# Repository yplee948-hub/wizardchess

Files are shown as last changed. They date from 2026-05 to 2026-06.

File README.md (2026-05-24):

# Wizard Chess

A Harry Potter-style physical chess board that moves pieces autonomously using an electromagnet on a CoreXY gantry. Players interact via voice command or a web UI — the board physically slides the pieces to match the move.

## How It Works

```
Browser (Next.js UI)
        │
        │  WebSocket (LAN)
        ▼
ESP32-S3 (control_firmware)   ◄──── I2S Microphone (voice → Whisper)
        │
        │  UART @ 115200
        ▼
Raspberry Pi Pico (motor_firmware)
        │
        ▼
CoreXY gantry + Electromagnet
```

1. A player speaks a move ("e2 to e4") or clicks it in the UI.
2. The **ESP32-S3** transcribes voice via OpenAI Whisper (or receives it over WebSocket) and forwards it to the Pico.
3. The **Pico** validates the move, plans the physical path, and drives the CoreXY stepper motors and electromagnet to move the piece.
4. Game state lives on the Pico and is relayed back to the UI in real time.

## Repository Structure

```
wizardchess/
├── motor_firmware/      # Raspberry Pi Pico — CoreXY motion + chess game logic
├── control_firmware/    # Seeed XIAO ESP32-S3 — voice + WebSocket bridge (ESP-NOW to motor)
├── UI/                  # Next.js web UI + WebSocket broker (only copy — do not duplicate)
├── prints/              # KiCad PCB + gerbers (STLs on OneDrive)
└── README.md            # This file
```

> **Web UI:** Use the `UI/` folder only. If you download a separate “web interface” zip, merge into `UI/` or replace it — do not add a second top-level copy.

## Hardware Required

| Component | Role |
|---|---|
| Raspberry Pi Pico (RP2040) | Motor control + game logic |
| Seeed XIAO ESP32-S3 | Voice recognition + Wi-Fi bridge |
| 2× Stepper motors (+ driver) | CoreXY X/Y motion |
| Electromagnet (H-bridge driven) | Piece pickup |
| ICS-43432 I2S microphone | Voice input |
| Custom motor PCB | Integrates Pico + drivers |

## Quick Start

See the README in each subdirectory for full setup instructions:

- [`motor_firmware/`](motor_firmware/README.md) — flash the Pico first
- [`control_firmware/`](control_firmware/README.md) — flash the ESP32-S3 second
- [`UI/`](UI/README.md) — run the web interface last
## Fabrication Files (Prints)

STL models, resin slicer files (.ctb), KiCad PCB, laser cut SVGs, and Fusion 360 source files are stored on OneDrive (too large for git):

**[Open OneDrive folder](https://uwnetid-my.sharepoint.com/:f:/r/personal/ktaing_uw_edu/Documents/wizard_chess?csf=1&web=1&e=kmWmI7)**

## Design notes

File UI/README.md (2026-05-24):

# Wizard Chess — Web UI

Next.js app for the physical board: intro screen, playable board, Stockfish opponent, and a WebSocket broker that talks to the ESP32-S3 control firmware.

## Prerequisites

- Node.js 20+
- ESP32-S3 flashed with [`control_firmware`](../control_firmware/README.md) (set `UI_SERVER_IP` in `config.h` to this machine’s LAN IP)

## Setup

```bash
cd UI
npm install
cp ../control_firmware/src/config.h.example ../control_firmware/src/config.h   # if not done yet — edit Wi‑Fi/API keys on the ESP32 side
```

Optional env (`.env.local`):

| Variable | Default | Purpose |
|---|---|---|
| `PORT` | `3000` | Next.js HTTP |
| `BROKER_PORT` | `3001` | WebSocket broker |
| `NEXT_PUBLIC_WS_URL` | `ws://<hostname>:3001/ws` | Override WS URL in the browser |

## Run

```bash
npm run dev
```

- UI: http://localhost:3000  
- Broker: `ws://localhost:3001/ws` (browser) · `ws://<your-lan-ip>:3001/device` (ESP32)

Open the UI from another device on the same Wi‑Fi using `http://<laptop-ip>:3000` — the client picks up the broker host automatically.

## Scripts

| Command | Description |
|---|---|
| `npm run dev` | UI + broker (`server.mjs`) |
| `npm run build` | Production Next.js build |
| `npm run start` | Production UI + broker |
| `npm run lint` | ESLint |
| `node test-device.mjs` | Quick broker/device smoke test |

## Layout

```
UI/
├── app/              # Next.js App Router (intro + /game)
├── public/           # SVG pieces, intro assets, Stockfish WASM
├── scripts/          # Stockfish copy helper, ws-test.html
├── server.mjs        # HTTP (3000) + WebSocket broker (3001)
└── test-device.mjs   # Broker connectivity helper
```

See [root README](../README.md) for full system architecture and flash order.

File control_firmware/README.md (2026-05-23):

# Control Firmware

Runs on the **Seeed XIAO ESP32-S3**. Acts as the central brain: transcribes voice commands via OpenAI Whisper, hosts a WebSocket server for the web UI, and relays everything to the Pico over UART.

## What It Does

- Listens for a button press, records up to 3 seconds of audio via I2S microphone
- Sends the audio to OpenAI Whisper and parses the transcript for a chess move ("e2 to e4")
- Hosts a WebSocket server so the Next.js UI can send moves and receive live game events
- Forwards move commands to the Pico (`MOVE:E2:E4`) and relays Pico responses back to the UI
- Voice and UI commands are interchangeable — the Pico can't tell them apart

## Hardware

**Board:** Seeed XIAO ESP32-S3

| Component | Pins |
|---|---|
| I2S Mic DOUT / BCLK / LRCLK | D0, D1, D2 |
| Record button (BOOT, active LOW) | D3 |
| UART TX to Pico / RX from Pico | D4, D5 |

**Required hardware:**
- ICS-43432 (or compatible) I2S MEMS microphone
- Wi-Fi access to the same LAN as the laptop running the UI

## Configuration

Credentials are kept out of source control. Before building:

```bash
cp src/config.h.example src/config.h
```

Edit `src/config.h`:

```cpp
#define WIFI_SSID       "your_network_name"
#define WIFI_PASSWORD   "your_wifi_password"
#define OPENAI_API_KEY  "sk-proj-..."
```

`src/config.h` is gitignored and will never be committed.

## Building & Flashing

Requires [PlatformIO](https://platformio.org/).

```bash
cd control_firmware
pio run --target upload
```

Update the upload port in `platformio.ini` if `/dev/cu.usbmodem14301` doesn't match your system.

**Dependencies** (auto-installed):
- `bblanchon/ArduinoJson`
- `mathieucarbou/AsyncTCP`
- `mathieucarbou/ESPAsyncWebServer`

## Usage

1. Flash the firmware and open a serial monitor at **115200 baud**.
2. The ESP32 connects to Wi-Fi and prints its IP address — note it for the UI.
3. Press the **BOOT button** to record a move. Speak clearly: *"e2 to e4"*.
4. The firmware transcribes, parses, and sends the move to the Pico automatically.

Alternatively, the Next.js UI connects to `ws://<esp32-ip>/ws` and sends moves directly.

## WebSocket API

The ESP32 hosts a WebSocket at `ws://<device-ip>/ws`.

### UI → ESP32

```json
{ "type": "move",  "from": "E2", "to": "E4" }
{ "type": "reset" }
{ "type": "hello" }
```

### ESP32 → UI

```json
{ "type": "ack",     "from": "E2", "to": "E4" }
{ "type": "illegal", "from": "E2", "to": "E4", "reason": "..." }
{ "type": "done",    "from": "E2", "to": "E4" }
{ "type": "turn",    "color": "WHITE" }
{ "type": "state",   "board": "rnbqkbnr...w" }
{ "type": "log",     "text": "..." }
```

## Source Layout

```
src/
├── main.cpp        # Button handler, recording pipeline, Whisper call, move parser
├── pico_link.cpp/h # UART protocol to/from the Pico
├── ui_link.cpp/h   # WebSocket server (ESPAsyncWebServer)
└── config.h        # Credentials (gitignored — copy from config.h.example)
```

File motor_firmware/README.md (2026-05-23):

# Motor Firmware

Runs on the **Raspberry Pi Pico (RP2040)**. Owns the chess game state, validates moves, plans the physical piece path, and drives the CoreXY gantry and electromagnet.

## What It Does

- Maintains a full chess game (legal move validation, turn tracking, board state)
- Receives move commands from the ESP32-S3 over UART (`MOVE:E2:E4`)
- Plans the physical path — routing around pieces, lifting/lowering the electromagnet
- Drives two stepper motors in CoreXY kinematics to move the carriage
- Emits game events back to the ESP32-S3 (`ACK`, `DONE`, `TURN`, `STATE`)

## Hardware

**Board:** Raspberry Pi Pico (RP2040)

| Component | Pins (GPIO) |
|---|---|
| Motor A (enable / step / dir) | GPIO 2, 3, 4 |
| Motor B (enable / step / dir) | GPIO 18, 19, 20 |
| Electromagnet (IN1 / IN2 / ENA) | GPIO 6, 7, 8 |
| UART to ESP32-S3 (TX / RX) | Serial2 (GPIO 4/5 default) |

**Motion specs:**
- Travel: ~41 cm × 41 cm
- Steps per axis: 16,400
- Square origin A1: (2.5 cm, 2.5 cm) from home
- Square spacing: 5.0 cm per column and row

## Building & Flashing

Requires [PlatformIO](https://platformio.org/) (CLI or VS Code extension).

```bash
cd motor_firmware
pio run --target upload
```

The board and upload port are set in `platformio.ini` (`board = pico`, port `/dev/cu.usbmodem144401`). Update the port to match your system if needed.

**Dependencies** (auto-installed by PlatformIO):
- `adafruit/Adafruit VEML7700 Library`

## UART Protocol

The Pico communicates with the ESP32-S3 over UART at **115200 baud**.

### Incoming (ESP32-S3 → Pico)

| Message | Meaning |
|---|---|
| `MOVE:<from>:<to>` | e.g. `MOVE:E2:E4` |
| `RESET` | Reset the game to starting position |
| `STATE?` | Request a full board state dump |

### Outgoing (Pico → ESP32-S3)

| Message | Meaning |
|---|---|
| `ACK:<from>:<to>` | Move accepted, motion starting |
| `DONE:<from>:<to>` | Motors finished, piece placed |
| `ILLEGAL:<reason>` | Move rejected |
| `TURN:<WHITE\|BLACK>` | Turn changed |
| `STATE:<board> <w\|b>` | 64-char board snapshot + side to move |
| `LOG:<text>` | Debug message |

## Source Layout

```
src/
├── main.cpp          # Setup, UART command dispatch, move loop
├── ChessGame.cpp/h   # Chess rules and board state
├── ChessTypes.h      # Piece and square types
├── CoreXY.cpp/h      # CoreXY kinematics
├── MovePlanner.cpp/h # Physical path planning around pieces
├── StepperMotor.cpp/h# Low-level stepper driver
└── Electromagnet.h   # Electromagnet H-bridge control
```

## Debugging

Open a serial monitor at **115200 baud** on the Pico's USB port. Protocol lines (`ACK`, `DONE`, etc.) go to `Serial2` (UART to ESP32); debug logs go to USB `Serial`.

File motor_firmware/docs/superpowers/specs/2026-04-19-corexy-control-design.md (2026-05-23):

# CoreXY Motion Control — Design

**Date:** 2026-04-19
**Target board:** Seeed XIAO ESP32-S3 (PlatformIO / Arduino)
**Scope:** High-level C++ API to drive a CoreXY rig using two existing `StepperMotor` instances.

## Goals

- Command motion by absolute XY coordinates in raw motor steps (no millimeter calibration).
- Produce straight-line motion at arbitrary angles (not L-shape).
- Support manual homing and soft limits (no physical endstops).
- Keep the API small, blocking, and easy to use from `main.cpp`.

## Non-goals

- No G-code parser, no serial command interface.
- No mm / physical-unit conversion.
- No per-move acceleration profile (fixed cruise speed only).
- No non-blocking / background motion.
- No physical limit switches.

## Architecture

Two components, cleanly separated:

1. **`StepperMotor`** (existing) — one new method added. Everything else unchanged.
   - New: `void stepOnce()` — strobes STEP HIGH for ~2 µs then LOW, increments the step counter. No cruise delay.
   - Existing `step()`, `steps()`, `rampUp()`, `setSpeed()`, `setDirection()`, `enable()`, `disable()`, `begin()` stay intact and usable for single-motor testing.

2. **`CoreXY`** (new) — composes two `StepperMotor` references, applies CoreXY kinematics, runs coordinated blocking moves, tracks position, enforces soft limits.

### Files

- `src/StepperMotor.h` / `src/StepperMotor.cpp` — add `stepOnce()`.
- `src/CoreXY.h` / `src/CoreXY.cpp` — new.
- `src/main.cpp` — rewrite to use `CoreXY`; keeps the existing `motorA(D4,D5,D6)` and `motorB(D9,D8,D7)` instances.

## Public API

```cpp
class CoreXY {
public:
    CoreXY(StepperMotor& motorA, StepperMotor& motorB);

    void begin();                              // enables both motors
    void setSpeed(int stepsPerSec);            // default 1500; applies to the next move

    void setInvertX(bool inv);                 // flip X direction sense in software
    void setInvertY(bool inv);                 // flip Y direction sense in software

    // Homing & bounds (no physical endstops)
    void setHome();                            // current position becomes (0, 0)
    void setMaxBounds(long xMax, long yMax);   // soft limits; 0 on an axis disables that bound
    void clearBounds();                        // remove all soft limits

    // Motion (blocking)
    void moveTo(long x, long y);               // absolute, coordinated straight line
    void moveBy(long dx, long dy);             // relative

    // State
    long getX() const;
    long getY() const;

    void disable();                            // disables both motor drivers
};
```

## Behavior

### Homing

- There are no physical switches. The user jogs (or places) the head at a chosen corner and calls `setHome()`, which zeroes the internal position.
- `setMaxBounds(xMax, yMax)` is called once (hardcoded after one-time manual calibration of the physical travel).

### Bounds enforcement

- `moveTo(x, y)` and `moveBy(dx, dy)` check the target against `[0..xMax, 0..yMax]` **before** moving.
- If the target is out of bounds, the call **refuses**: no steps issued, position unchanged, a short warning printed to `Serial` (e.g. `"[CoreXY] refused: target (1200, 0) out of bounds"`).
- `setMaxBounds(0, 0)` or never calling `setMaxBounds` means no limits — any target is accepted, including negative coordinates. User accepts responsibility for not crashing the head into the frame.

### Direction inversion

- `setInvertX(bool)` and `setInvertY(bool)` flip the sign of `ΔX` / `ΔY` in the kinematics calculation only. Internal position remains in user coordinates (so `moveTo(100, 0)` always means "go to X=100 in user space").
- Used to correct belt / wiring direction in software without changing hardware.

### Motor mapping

- `motorA` = first ctor argument; `motorB` = second.
- In the starter `main.cpp`: `motorA = StepperMotor(D4, D5, D6)`, `motorB = StepperMotor(D9, D8, D7)`.

## Kinematics & Stepping Algorithm

### Inverse kinematics

After applying inversion flags:

```
ΔA = ΔX + ΔY
ΔB = ΔX − ΔY
```

Direction pins are set once per move from the signs of `ΔA` and `ΔB`.

### Straight-line stepping (Bresenham)

CoreXY kinematics is linear, so a straight line in motor-step space `(A, B)` maps to a straight line in `(X, Y)`. Standard Bresenham:

- `aA = |ΔA|`, `aB = |ΔB|`.
- The axis with the larger step count is the "fast" axis; it pulses every iteration.
- The "slow" axis pulses only when an error accumulator overflows.
- Total iterations = `max(aA, aB)`.

### Timing

- `stepOnce()` on each motor does a ~2 µs STEP pulse (well above the minimum for A4988 / DRV8825 / TMC2208 drivers) and returns immediately.
- Between iterations, `CoreXY::moveTo()` calls `delayMicroseconds(period)` where `period = 1,000,000 / stepsPerSec`. At 1500 steps/sec → ~666 µs per iteration.
- Direction pins are set **once** at the start of the move.

### Edge cases

- `ΔA == 0 && ΔB == 0` → return immediately.
- Small moves (1–2 steps) → still go through the Bresenham loop; correct by construction.
- Position updates **only** after the loop completes successfully.

## `main.cpp` shape

```cpp
#include <Arduino.h>
#include "StepperMotor.h"
#include "CoreXY.h"

StepperMotor motorA(D4, D5, D6);
StepperMotor motorB(D9, D8, D7);
CoreXY xy(motorA, motorB);

void setup() {
    Serial.begin(115200);
    xy.begin();
    xy.setSpeed(1500);
    xy.setHome();
    // xy.setMaxBounds(5000, 3000);  // fill in after manual calibration

    xy.moveTo(1000, 0);
    xy.moveTo(1000, 1000);
    xy.moveTo(0, 1000);
    xy.moveTo(0, 0);
}

void loop() {}
```

## Testing plan

No host-side unit tests; validation is on the physical rig:

1. **Single-motor sanity** — confirm both motors spin correctly using the existing `StepperMotor` API in isolation.
2. **Pure-X move** — `moveTo(500, 0)`. Both motors step 500 in the same direction. Head moves along X. If it moves in Y, use `setInvertX` / `setInvertY` or re-pick which motor is A / B.
3. **Pure-Y move** — `moveTo(0, 500)`. Both motors step 500 in opposite directions. Head moves along Y.
4. **Diagonal** — `moveTo(500, 500)`. Motor A steps 1000, motor B steps 0. Head moves diagonally.
5. **Square** — run the demo in `main.cpp`; verify the head returns to the starting point (loop closes).
6. **Bounds** — `setMaxBounds(500, 500)` then `moveTo(1000, 0)` → serial prints a refusal; position unchanged.

## Open items / future work

- Non-blocking motion (`tick()`-driven) if later work needs to run sensors concurrently with motion.
- Trapezoidal acceleration per move if higher step rates cause skipped steps.
- Physical endstops + `home()` that actually drives into them, if the rig gains switches.

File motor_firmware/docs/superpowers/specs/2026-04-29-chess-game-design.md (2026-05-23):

# Chess Game Class Design

**Date:** 2026-04-29
**Project:** TECHIN 515 Group Final — Physical Chess Robot (CoreXY + Electromagnet)

---

## Overview

Two new C++ classes — `ChessGame` and `MovePlanner` — manage chess game state and physical move execution respectively. They are decoupled from `CoreXY` and `Electromagnet`: they produce data (board state, step sequences) that `main.cpp` acts on. This separation allows the classes to be tested on a PC or microcontroller without any motor hardware attached.

---

## Shared Types (`ChessTypes.h`)

```cpp
enum PieceType  { NONE, PAWN, ROOK, KNIGHT, BISHOP, QUEEN, KING };
enum PieceColor { WHITE, BLACK, NO_COLOR };

struct Piece    { PieceType type; PieceColor color; };
struct Position { char col; int row; };  // col 'A'–'H', row 1–8

struct PhysicalConfig {
    float originX, originY;  // physical XY of A1 in cm
    float stepX,   stepY;    // cm per square
};

enum StepType { MOVE_TO, MAGNET_ON, MAGNET_OFF };
struct Step   { StepType type; Position target; float x; float y; };
// x and y are only meaningful for MOVE_TO steps; set to 0 for MAGNET_ON/MAGNET_OFF
```

---

## `ChessGame`

### Responsibility
Owns the board state and enforces chess rules. Does not touch hardware or compute physical paths.

### Data
- `Piece board[8][8]` — 2D array indexed by column (0–7) and row (0–7)
- `PieceColor turn` — whose turn it is
- `std::vector<Piece> captured` — pieces that have been taken off the board

### Constructor / Initialization
```cpp
ChessGame();                        // standard starting position
ChessGame(Piece board[8][8]);       // custom starting position
void reset();                       // restore standard starting position
```

### Key Methods
```cpp
bool      isLegalMove(Position from, Position to);  // validates piece rules, turn, capture legality
bool      applyMove(Position from, Position to);    // updates board after physical move completes
PieceColor getTurn();
Piece     getPieceAt(Position pos);
bool      isEmpty(Position pos);
std::vector<Piece> getCaptured();
```

### Rules Implemented (core moves)
- Each piece type moves according to standard chess movement patterns
- A piece may not move to a square occupied by a friendly piece
- Capturing: moving to a square occupied by an enemy piece is legal (per piece rules)
- Turn alternation: WHITE moves first, turns alternate after each `applyMove()`
- **Not implemented:** castling, en passant, pawn promotion, check/checkmate/stalemate detection

### Notes
- `applyMove()` is called internally by `MovePlanner` at the moment `isMoveDone()` becomes true, keeping the board in sync with physical reality. `main.cpp` does not call it directly.
- Knight movement is rectilinear at the rules level (L-shape) but the physical path is still handled as rectilinear waypoints by `MovePlanner`.

---

## `MovePlanner`

### Responsibility
Holds a reference to `ChessGame` to read board state, computes a rectilinear physical path for a validated move, manages displaced and captured pieces, and exposes a step-by-step execution interface for sensor integration.

### Data
- `ChessGame& game` — reference to the game state
- `PhysicalConfig config` — physical grid constants
- `std::queue<Step> steps` — planned step sequence for the current move
- `BorderSlots capturedSlots` — registry of occupied/free parking slots around the board edge for captured pieces

### Physical Coordinate Mapping
```
physicalX(pos) = config.originX + (pos.col - 'A') * config.stepX
physicalY(pos) = config.originY + (pos.row - 1)  * config.stepY
```
Default values from current `main.cpp`: `originX=3.8`, `originY=5.5`, `stepX=5.0`, `stepY=5.0`.

### Path Planning Rules
- Paths are strictly rectilinear (horizontal then vertical, or vertical then horizontal — no diagonal movement)
- Direction chosen to minimize the number of blocking pieces on the primary leg
- For each blocking piece along the path: park it on the nearest orthogonally adjacent empty square (up/down/left/right only, no diagonal), complete the main move, then restore it
- Captured pieces are parked in the next free border slot around the board and tracked permanently

### Step Sequence (per move)
Each move compiles to an ordered queue of `Step` entries:
1. Sub-sequences for each blocking piece (MAGNET_ON → MOVE_TO park square → MAGNET_OFF)
2. MAGNET_ON → MOVE_TO destination → MAGNET_OFF for the main piece
3. Sub-sequences to restore each displaced blocking piece
4. If a capture: the captured piece sub-sequence runs before step 2, parking it at the border

### Key Methods
```cpp
MovePlanner(ChessGame& game, PhysicalConfig config);

bool startMove(Position from, Position to);  // plan full path; returns false if illegal
bool nextStep();                             // execute one Step, return true if more remain
bool isMoveDone();                           // true when step queue is empty
Step peekNextStep();                         // inspect next Step without advancing (for sensor hook)
```

### Sensor Integration Hook (future)
```cpp
// In main.cpp loop:
Step s = planner.peekNextStep();
// read hall effect sensor here — confirm piece presence if s.type == MOVE_TO
planner.nextStep();
// then act: xy.moveToCm(s.x, s.y) or magnet.on()/off()
```

---

## Integration in `main.cpp`

```cpp
ChessGame game;
MovePlanner planner(game, {3.8f, 5.5f, 5.0f, 5.0f});

// To make a move:
if (planner.startMove({'E', 2}, {'E', 4})) {
    while (!planner.isMoveDone()) {
        Step s = planner.peekNextStep();
        planner.nextStep();
        if (s.type == MOVE_TO)      xy.moveToCm(s.x, s.y);
        else if (s.type == MAGNET_ON)  magnet.on();
        else if (s.type == MAGNET_OFF) magnet.off();
    }
}
```

---

## File Structure

```
src/
  ChessTypes.h      — shared enums and structs
  ChessGame.h
  ChessGame.cpp
  MovePlanner.h
  MovePlanner.cpp
```

---

## Out of Scope (this spec)

- Castling, en passant, pawn promotion
- Check, checkmate, stalemate detection
- AI / computer opponent
- Hall effect sensor driver (integration point is defined, not implemented)

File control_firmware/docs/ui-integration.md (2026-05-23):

# UI ↔ ESP32-S3 ↔ Pico Integration — Design

## Goal

Let a Next.js chess UI drive (and stay in sync with) the physical board, while keeping the existing ESP32-S3 microphone input working. The ESP32-S3 is the brain: it accepts commands from both the UI and the mic, forwards canonical moves to the Pico, and relays the Pico's game-state feedback back up to the UI.

## Topology (LAN-only, no cloud)

```mermaid
flowchart LR
    UI["Next.js<br/>(browser)"]
    S3["ESP32-S3<br/>(brain + mic)"]
    Pico["Pico<br/>(motors + game)"]

    UI <-- "WebSocket (LAN)" --> S3
    S3 <-- "UART" --> Pico
```

- The laptop running `next dev` and the ESP32-S3 share the same Wi-Fi network.
- The ESP32-S3 runs a WebSocket server on its LAN IP, e.g. `ws://<s3-ip>/ws`.
- No remote server, no port forwarding, no auth (demo scope).
- Fallback option if venue Wi-Fi is hostile: run the S3 as a Wi-Fi Access Point ("ChessBot-AP") and have the laptop join it. Same protocol, different network plumbing.

## Source of truth

- **Game state lives on the Pico.** It already has `ChessGame` and a working move planner; we don't want two copies that can drift.
- The ESP32-S3 caches the last `STATE` message it saw from the Pico so it can hand it to a UI client that just connected. It is a relay + cache, not an authority.
- The UI waits for an `ACK` (or `ILLEGAL`) before animating a move. No optimistic UI for the demo — simpler and more honest about what the hardware actually did.

## Pico ↔ ESP32-S3: UART line protocol

Both sides at 115200 8N1 on the existing UART. Lines terminated with `\n`. Case-insensitive on the Pico side (it already uppercases input). Keep the protocol ASCII so it's debuggable with a serial monitor.

### S3 → Pico (commands)

| Line | Meaning |
|---|---|
| `MOVE:<from>:<to>` | e.g. `MOVE:E2:E4` |
| `RESET` | reset the game |
| `STATE?` | request a `STATE:` dump (for resync) |

### Pico → S3 (events)

| Line | Meaning |
|---|---|
| `ACK:<from>:<to>` | move accepted, motion starting |
| `ILLEGAL:<reason>` | move rejected by `ChessGame` or planner |
| `DONE:<from>:<to>` | motors + magnet finished the move |
| `TURN:<WHITE\|BLACK>` | turn changed (emitted after `DONE` and after `RESET`)  |
| `STATE:<compact-board>` | full board snapshot; emitted on boot, `RESET`, `STATE?`|
| `LOG:<text>` | optional human-readable diagnostics |

The `STATE` payload format is TBD — simplest is 64 chars in row-major order using standard piece letters (`PNBRQK`/`pnbrqk`/`.`), plus a trailing turn marker, e.g. `STATE:rnbqkbnr/...whatever... w`. FEN is fine if it's cheap to emit; we don't need castling/en-passant rights for the demo unless the game logic enforces them.

### Pico-side changes

- Today's `main.cpp` reads `MOVE:<from>:<to>` from `Serial1`. Keep that.
- Wrap the existing `Serial.print*` debug output into a small helper so the *protocol* lines (`ACK`, `DONE`, `STATE`, …) go to `Serial1` and casual debug logs go to USB `Serial` only. Mixing them on one stream is fine for the demo but easier to parse if separated.
- Emit `ACK` immediately after `planner.startMove` succeeds, `DONE` after the planner loop finishes, `TURN` after the turn flips, and `STATE` on boot / after `RESET` / on `STATE?`.

## ESP32-S3 ↔ UI: WebSocket protocol

JSON messages over a single WebSocket. The S3 hosts it (e.g. `ESPAsyncWebServer` + `AsyncWebSocket`). One endpoint, all traffic.

### UI → S3

```json
{ "type": "move",  "from": "E2", "to": "E4" }
{ "type": "reset" }
{ "type": "hello" }    // optional; S3 replies with current state
```

### S3 → UI

```json
{ "type": "ack",     "from": "E2", "to": "E4" }
{ "type": "illegal", "from": "E2", "to": "E4", "reason": "..." }
{ "type": "done",    "from": "E2", "to": "E4" }
{ "type": "turn",    "color": "WHITE" }
{ "type": "state",   "board": "<compact-or-fen>", "turn": "WHITE" }
{ "type": "log",     "text": "..." }              // optional
```

The mapping S3 does is mechanical: parse the UART line, wrap it as JSON, broadcast to all connected WS clients. In the other direction: parse JSON, format the UART line, write to the Pico. The S3 also handles the mic path the same way — mic recognizer produces a `{from, to}` pair, S3 sends `MOVE:` down. Voice and UI commands are indistinguishable to the Pico, which is the point.

### Connection lifecycle

1. UI opens the WebSocket.
2. S3 immediately sends the cached `state` (and current `turn`) so the new client renders the right board without polling.
3. UI sends `move` / `reset`; S3 forwards to Pico.
4. Pico replies with `ack` → `done` → `turn`; S3 fans those out to *all* WS clients (so two browsers on the same LAN stay in sync, and the UI reflects voice-initiated moves the same way).

## ESP32-S3 internal shape

Three input sources, one output (UART to Pico):

- Mic recognizer task → produces `{from, to}` or `reset`.
- WebSocket handler → produces `{from, to}` or `reset` from JSON.
- UART reader → produces parsed events from the Pico.

A small dispatcher serializes commands going *down* (don't interleave a mic move and a UI move mid-line) and broadcasts events going *up*. While a move is in flight (between `ACK` and `DONE`), new commands should be queued or rejected — TBD which; rejection with an `illegal` reason of `"busy"` is the simpler choice.

State cached on the S3:
- Last `state` payload (string).
- Current `turn`.
- Whether a move is in flight.

## Next.js side

- A single client component opens the WebSocket to `NEXT_PUBLIC_S3_WS_URL` (e.g. `ws://192.168.1.42/ws`) and keeps it open for the page's lifetime. Reconnect with backoff on close.
- Board state is driven entirely by `state` / `done` / `turn` messages — the UI does not maintain its own authoritative game state.
- Clicking a piece + target square sends `{ "type": "move", from, to }`. The UI marks the move as "pending" until `ack`/`illegal` arrives, then animates on `done`.
- A "Reset" button sends `{ "type": "reset" }`.

No Node API routes, no `serialport`, no server-side code beyond what Next already does to serve the page. All hardware I/O is in the S3.

## Decisions (locked for the POC)

- **`STATE` payload**: 64 chars, row-major from rank 8 down to rank 1, piece letters (`PNBRQK` white, `pnbrqk` black, `.` empty), followed by a space and the side to move (`w`/`b`). Whatever is cheapest to emit from `ChessGame`.
- **Busy**: while a move is in flight (between `ACK` and `DONE`), any new command is rejected with `ILLEGAL:busy`. No queue.
- **Promotion**: out of scope for the POC.
- **Discovery**: S3's IP is hardcoded in the Next.js client for the demo. S3 also prints its IP over USB serial on boot for convenience.

## Build order (suggested)

1. Pico: extend the UART protocol with `ACK` / `DONE` / `TURN` / `STATE` / `STATE?` / `ILLEGAL`. Verify with a serial monitor by hand.
2. ESP32-S3: bring up Wi-Fi + WebSocket server, echo UART events as JSON, accept UI commands and forward as UART lines. Verify with a tiny HTML test page or `wscat`.
3. Integrate the mic recognizer into the same dispatcher.
4. Next.js: wire the WS client into the board UI; remove any local game-state simulation.

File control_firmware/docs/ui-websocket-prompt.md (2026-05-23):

You're updating an existing Next.js chess board UI to drive a real chess robot over a WebSocket. The robot is an ESP32-S3 on the same LAN that hosts a single WebSocket endpoint and relays everything to/from a Raspberry Pi Pico that owns the actual game state.

## Endpoint

- URL: `ws://<S3_IP>/ws` — single endpoint, all traffic.
- Read the IP from `process.env.NEXT_PUBLIC_S3_WS_URL` (full `ws://…/ws` URL). Default to `ws://192.168.1.42/ws` if unset.
- The S3 prints its IP over USB serial on boot.

## Protocol — UI → S3 (you send these)

```json
{ "type": "move",  "from": "E2", "to": "E4" }
{ "type": "reset" }
{ "type": "hello" }
```

- `from`/`to` are uppercase algebraic squares ("A1"–"H8").
- `hello` is optional; on a fresh connection the S3 will already replay cached state.

## Protocol — S3 → UI (you receive these)

```json
{ "type": "ack",     "from": "E2", "to": "E4" }
{ "type": "done",    "from": "E2", "to": "E4" }
{ "type": "illegal", "reason": "..." }
{ "type": "turn",    "color": "WHITE" }
{ "type": "state",   "board": "<64chars>", "turn": "WHITE" }
{ "type": "log",     "text": "..." }
```

- `state.board` is 64 chars, row-major from rank 8 down to rank 1, piece letters `PNBRQK` (white) / `pnbrqk` (black) / `.` (empty). No slashes, no FEN — just the 64 chars.
- `state.turn` and `turn.color` are `"WHITE"` or `"BLACK"`.
- `illegal` does **not** carry from/to — correlate it with the move you most recently sent.
- Starting-position `state.board` is `"rnbqkbnrpppppppp................................PPPPPPPPRNBQKBNR"`.

## Connection lifecycle

1. UI opens the socket.
2. S3 immediately pushes the cached `state` and last `turn` (no need to send `hello` first). If the S3 has nothing cached yet, nothing arrives — request with `hello` to retry.
3. UI sends `move` or `reset`.
4. Sequence on a successful move: `ack` → `done` → `turn`. On a rejected move: `illegal` only.
5. Sequence on reset: `state` → `turn`.

## Behavioral requirements

- **No optimistic UI.** Mark the move "pending" the moment you send it; render the board change only on `done`. On `illegal`, revert/clear the pending state and show the reason.
- **Board state is not authoritative on the client.** Drive it entirely from `state` / `done` / `turn`. Do not maintain a parallel game model — the Pico is the source of truth.
- **Multi-source.** The board can change from voice input on the device, not just from this UI. Treat every incoming `done` / `state` / `turn` as ground truth and re-render. Two browsers connected at once should stay in sync.
- **Reconnect.** On socket close, reconnect with exponential backoff (start 500 ms, cap 10 s, jitter optional). On reconnect, the S3 will replay cached `state` automatically.
- **Reset button.** Sends `{"type":"reset"}` and waits for the resulting `state` to repaint.

## Constraints

- Single client component owns the socket for the page's lifetime.
- No Node API routes, no server-side WebSocket code — direct browser → S3.
- Don't add auth or queueing.

## Acceptance

- Loading the page connects to the S3 and renders the current board within ~1 s.
- Clicking a piece + target square sends `move`, shows pending state, then animates on `done`.
- A second browser tab on the same LAN reflects the same moves in real time.
- Saying a move out loud at the device produces the same updates in the UI without anything being clicked.
- Pulling the S3's power and bringing it back recovers the connection automatically.

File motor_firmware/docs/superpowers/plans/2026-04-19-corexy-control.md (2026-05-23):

# CoreXY Motion Control Implementation Plan

> **For agentic workers:** REQUIRED SUB-SKILL: Use superpowers:subagent-driven-development (recommended) or superpowers:executing-plans to implement this plan task-by-task. Steps use checkbox (`- [ ]`) syntax for tracking.

**Goal:** Build a blocking high-level C++ API (`CoreXY`) that drives two stepper motors to produce straight-line coordinated motion in motor-step coordinates on a Seeed XIAO ESP32-S3.

**Architecture:** Add a `stepOnce()` primitive to the existing `StepperMotor` class (no cruise delay, just a short STEP strobe). Introduce a new `CoreXY` class that composes two `StepperMotor` references, applies CoreXY inverse kinematics (ΔA = ΔX + ΔY, ΔB = ΔX − ΔY), and interleaves motor pulses with Bresenham's line algorithm so the head moves in a straight line for any (X, Y) target. Soft bounds and software direction inversion are tracked in state. All motion is blocking.

**Tech Stack:** PlatformIO, Arduino framework, ESP32 (Seeed XIAO ESP32-S3), C++. No host-side test framework — validation is on the physical rig via Serial logging and visual observation.

**Notes for implementer:**
- This project is **not a git repo**. Skip all `git add` / `git commit` steps unless the user initializes one. Treat each task's end as "build + upload + verify," not "commit."
- Build: `pio run` (from project root). Upload: `pio run -t upload`. Monitor serial: `pio device monitor -b 115200`.
- The `lib/light.cpp` file is unrelated (VEML7700 light sensor demo). Don't touch it, and don't worry if it isn't picked up by the build — PlatformIO's lib dependency finder skips bare files directly under `lib/`.
- CoreXY kinematics, brief refresher: the two belts are routed so that **both** motors contribute to every axis. The inverse map is `ΔA = ΔX + ΔY`, `ΔB = ΔX − ΔY`. So +X moves both motors the same direction, +Y moves them opposite directions, and a diagonal is "only one motor moves." This is why we need to interleave steps in the *right ratio* — step motor A to completion and then motor B would produce an L-shape on the rig, not a straight line.

---

## File Structure

- `src/StepperMotor.h` — **modify**: add `stepOnce()` declaration.
- `src/StepperMotor.cpp` — **modify**: add `stepOnce()` definition.
- `src/CoreXY.h` — **create**: new class.
- `src/CoreXY.cpp` — **create**: implementation.
- `src/main.cpp` — **rewrite**: demo sketch that exercises the new API.

---

## Task 1: Add `stepOnce()` primitive to `StepperMotor`

Gives CoreXY a short-pulse step primitive without the built-in cruise delay that the existing `step()` method has. ~2 µs HIGH strobe is safely above the minimum pulse width for A4988 / DRV8825 / TMC2208 drivers.

**Files:**
- Modify: `src/StepperMotor.h` (add one declaration around line 16)
- Modify: `src/StepperMotor.cpp` (add one definition at the end of the file)

- [ ] **Step 1: Add `stepOnce()` declaration to `StepperMotor.h`**

Open `src/StepperMotor.h`. In the `public:` section, directly after the existing `void steps(int n);` line, add:

```cpp
    void stepOnce();                 // single short STEP strobe, no delay; updates step counter
```

Final `public:` block should look like:

```cpp
    void begin();
    void enable();
    void disable();

    void setDirection(bool clockwise);
    void setSpeed(int stepsPerSec);  // sets cruise speed

    void rampUp(int accelSteps = 200);
    void step();                     // single step at cruise speed, call in loop()
    void steps(int n);               // blocking: run n steps at cruise speed
    void stepOnce();                 // single short STEP strobe, no delay; updates step counter

    int  getStepCount() const { return _stepCount; }
    void resetStepCount()    { _stepCount = 0; }
```

- [ ] **Step 2: Add `stepOnce()` definition to `StepperMotor.cpp`**

Append to the end of `src/StepperMotor.cpp`:

```cpp
void StepperMotor::stepOnce() {
    digitalWrite(_stepPin, HIGH);
    delayMicroseconds(2);
    digitalWrite(_stepPin, LOW);
    _stepCount++;
}
```

- [ ] **Step 3: Build to verify it compiles**

Run: `pio run`
Expected: `SUCCESS`. No errors. (The existing `main.cpp` doesn't call `stepOnce()` yet, so linking should still work.)

---

## Task 2: Create `CoreXY` class (header + empty implementation)

Get the class and all public method stubs in place and compiling. No real logic yet. This isolates the "does the project still build with the new class" concern from the logic.

**Files:**
- Create: `src/CoreXY.h`
- Create: `src/CoreXY.cpp`

- [ ] **Step 1: Create `src/CoreXY.h`**

Full contents:

```cpp
#pragma once
#include <Arduino.h>
#include "StepperMotor.h"

class CoreXY {
public:
    CoreXY(StepperMotor& motorA, StepperMotor& motorB);

    void begin();                              // enables both motors
    void setSpeed(int stepsPerSec);            // default 1500; applies to the next move

    void setInvertX(bool inv);                 // flip X direction sense in software
    void setInvertY(bool inv);                 // flip Y direction sense in software

    void setHome();                            // current position becomes (0, 0)
    void setMaxBounds(long xMax, long yMax);   // soft limits; 0 on an axis disables that bound
    void clearBounds();                        // remove all soft limits

    void moveTo(long x, long y);               // absolute, coordinated straight line (blocking)
    void moveBy(long dx, long dy);             // relative (blocking)

    long getX() const { return _x; }
    long getY() const { return _y; }

    void disable();                            // disables both motor drivers

private:
    StepperMotor& _motorA;
    StepperMotor& _motorB;

    long _x = 0;
    long _y = 0;

    int  _stepsPerSec = 1500;

    bool _invertX = false;
    bool _invertY = false;

    long _xMax = 0;   // 0 = no limit on this axis
    long _yMax = 0;   // 0 = no limit on this axis
};
```

- [ ] **Step 2: Create `src/CoreXY.cpp` with empty stubs**

Full contents:

```cpp
#include "CoreXY.h"

CoreXY::CoreXY(StepperMotor& motorA, StepperMotor& motorB)
    : _motorA(motorA), _motorB(motorB) {}

void CoreXY::begin() {}
void CoreXY::setSpeed(int stepsPerSec) { (void)stepsPerSec; }
void CoreXY::setInvertX(bool inv) { (void)inv; }
void CoreXY::setInvertY(bool inv) { (void)inv; }
void CoreXY::setHome() {}
void CoreXY::setMaxBounds(long xMax, long yMax) { (void)xMax; (void)yMax; }
void CoreXY::clearBounds() {}
void CoreXY::moveTo(long x, long y) { (void)x; (void)y; }
void CoreXY::moveBy(long dx, long dy) { (void)dx; (void)dy; }
void CoreXY::disable() {}
```

- [ ] **Step 3: Build to verify it compiles**

Run: `pio run`
Expected: `SUCCESS`. (Main still references `StepperMotor` only, so `CoreXY.cpp` compiles but isn't linked in yet — that's fine.)

---

## Task 3: Implement state management and configuration methods

Everything except the two motion methods. These are pure state setters / accessors with no timing or kinematics, so they're easy to verify by inspection.

**Files:**
- Modify: `src/CoreXY.cpp`

- [ ] **Step 1: Replace each stub with its real implementation**

Open `src/CoreXY.cpp`. Replace the file's contents (keeping the constructor as it is) with:

```cpp
#include "CoreXY.h"

CoreXY::CoreXY(StepperMotor& motorA, StepperMotor& motorB)
    : _motorA(motorA), _motorB(motorB) {}

void CoreXY::begin() {
    _motorA.begin();
    _motorB.begin();
    _motorA.enable();
    _motorB.enable();
}

void CoreXY::setSpeed(int stepsPerSec) {
    if (stepsPerSec > 0) {
        _stepsPerSec = stepsPerSec;
    }
}

void CoreXY::setInvertX(bool inv) { _invertX = inv; }
void CoreXY::setInvertY(bool inv) { _invertY = inv; }

void CoreXY::setHome() {
    _x = 0;
    _y = 0;
}

void CoreXY::setMaxBounds(long xMax, long yMax) {
    _xMax = xMax < 0 ? 0 : xMax;
    _yMax = yMax < 0 ? 0 : yMax;
}

void CoreXY::clearBounds() {
    _xMax = 0;
    _yMax = 0;
}

void CoreXY::moveTo(long x, long y) { (void)x; (void)y; }
void CoreXY::moveBy(long dx, long dy) { (void)dx; (void)dy; }

void CoreXY::disable() {
    _motorA.disable();
    _motorB.disable();
}
```

- [ ] **Step 2: Build to verify it compiles**

Run: `pio run`
Expected: `SUCCESS`.

---

## Task 4: Implement `moveTo()` — kinematics, bounds refusal, Bresenham stepping

The core of the library. Does four things in order:

1. Check soft bounds; refuse with Serial warning if out.
2. Compute motor-space deltas from XY deltas (apply inversion).
3. Set direction pins once based on delta signs.
4. Bresenham-interleave step pulses; `delayMicroseconds` between iterations to hit the configured step rate.

**Files:**
- Modify: `src/CoreXY.cpp` (replace the empty `moveTo` stub)

- [ ] **Step 1: Replace `moveTo()` stub with the real implementation**

In `src/CoreXY.cpp`, replace:

```cpp
void CoreXY::moveTo(long x, long y) { (void)x; (void)y; }
```

with:

```cpp
void CoreXY::moveTo(long x, long y) {
    // Soft-bounds refusal, per-axis. An axis with max == 0 is unbounded.
    bool outOfBounds = false;
    if (_xMax > 0 && (x < 0 || x > _xMax)) outOfBounds = true;
    if (_yMax > 0 && (y < 0 || y > _yMax)) outOfBounds = true;
    if (outOfBounds) {
        Serial.printf("[CoreXY] refused: target (%ld, %ld) out of bounds\n", x, y);
        return;
    }

    // Deltas in user space, then apply inversion for the motor-space math
    long dx = x - _x;
    long dy = y - _y;
    long dxEff = _invertX ? -dx : dx;
    long dyEff = _invertY ? -dy : dy;

    // CoreXY inverse kinematics
    long dA = dxEff + dyEff;
    long dB = dxEff - dyEff;

    if (dA == 0 && dB == 0) {
        return;
    }

    // Directions set once for the whole move
    _motorA.setDirection(dA >= 0);
    _motorB.setDirection(dB >= 0);

    long aA = dA >= 0 ? dA : -dA;
    long aB = dB >= 0 ? dB : -dB;

    long periodUs = 1000000L / _stepsPerSec;

    // Bresenham line in motor-step space. The "fast" axis (more steps) pulses every
    // iteration; the "slow" axis pulses only when the error accumulator overflows.
    if (aA >= aB) {
        long err = aA / 2;
        for (long i = 0; i < aA; i++) {
            _motorA.stepOnce();
            err -= aB;
            if (err < 0) {
                err += aA;
                _motorB.stepOnce();
            }
            delayMicroseconds(periodUs);
        }
    } else {
        long err = aB / 2;
        for (long i = 0; i < aB; i++) {
            _motorB.stepOnce();
            err -= aA;
            if (err < 0) {
                err += aB;
                _motorA.stepOnce();
            }
            delayMicroseconds(periodUs);
        }
    }

    _x = x;
    _y = y;
}
```

- [ ] **Step 2: Build to verify it compiles**

Run: `pio run`
Expected: `SUCCESS`.

---

## Task 5: Implement `moveBy()`

Thin wrapper — compute the absolute target and delegate to `moveTo()`. Inherits bounds refusal for free.

**Files:**
- Modify: `src/CoreXY.cpp`

- [ ] **Step 1: Replace `moveBy()` stub with the real implementation**

In `src/CoreXY.cpp`, replace:

```cpp
void CoreXY::moveBy(long dx, long dy) { (void)dx; (void)dy; }
```

with:

```cpp
void CoreXY::moveBy(long dx, long dy) {
    moveTo(_x + dx, _y + dy);
}
```

- [ ] **Step 2: Build to verify it compiles**

Run: `pio run`
Expected: `SUCCESS`.

---

## Task 6: Rewrite `main.cpp` as a CoreXY demo sketch

Swap the current "ramp up and spin" sketch for one that exercises the new API. This is the first end-to-end test — uploading this will actually drive the rig.

**Files:**
- Modify: `src/main.cpp` (full rewrite)

- [ ] **Step 1: Replace `src/main.cpp` with the demo sketch**

Full new contents of `src/main.cpp`:

```cpp
#include <Arduino.h>
#include "StepperMotor.h"
#include "CoreXY.h"

StepperMotor motorA(D4, D5, D6);
StepperMotor motorB(D9, D8, D7);
CoreXY xy(motorA, motorB);

void setup() {
    Serial.begin(115200);
    delay(1000);                 // give the serial monitor time to attach
    Serial.println("[CoreXY] boot");

    xy.begin();
    xy.setSpeed(1500);
    xy.setHome();

    // Uncomment and fill in after manually calibrating the physical travel:
    // xy.setMaxBounds(5000, 3000);

    Serial.println("[CoreXY] running square demo");
    xy.moveTo(1000, 0);
    Serial.printf("  at (%ld, %ld)\n", xy.getX(), xy.getY());
    xy.moveTo(1000, 1000);
    Serial.printf("  at (%ld, %ld)\n", xy.getX(), xy.getY());
    xy.moveTo(0, 1000);
    Serial.printf("  at (%ld, %ld)\n", xy.getX(), xy.getY());
    xy.moveTo(0, 0);
    Serial.printf("  at (%ld, %ld)\n", xy.getX(), xy.getY());

    Serial.println("[CoreXY] demo complete");
    xy.disable();
}

void loop() {}
```

- [ ] **Step 2: Build to verify the full project compiles and links**

Run: `pio run`
Expected: `SUCCESS`. A successful link proves `CoreXY.cpp` is now pulled into the build via `main.cpp`'s include.

- [ ] **Step 3: Upload and open serial monitor**

Run (in two separate terminals or sequentially):

```bash
pio run -t upload
pio device monitor -b 115200
```

Expected serial output:

```
[CoreXY] boot
[CoreXY] running square demo
  at (1000, 0)
  at (1000, 1000)
  at (0, 1000)
  at (0, 0)
[CoreXY] demo complete
```

**Physical expectation:** head traces a square and returns to start. If the square is rotated 45°, sheared, or traces an L-shape — stop, note which pattern, and proceed to Task 7 to debug with simpler moves.

---

## Task 7: Physical validation walkthrough

The previous task already runs a full demo. This task walks through the individual motion primitives one at a time so that if Task 6 looks wrong, you can localize the problem. These are substitutions into `setup()` — do them by temporarily editing `main.cpp`, uploading, observing, then restoring the square demo.

**Files:**
- Temporarily modify `src/main.cpp` for each sub-step; restore to the Task 6 demo at the end.

- [ ] **Step 1: Pure-X move test**

Replace the four `moveTo` calls in `setup()` with just:

```cpp
    xy.moveTo(500, 0);
```

Upload, observe.

**Expected:** both motors step 500 times in the same direction; head moves along one physical axis (call it the "X axis" of the rig).

**Failure modes and fixes:**
- Head moves along the Y axis instead → the library's X and Y are swapped relative to your rig. Swap which pins you pass to `motorA` vs `motorB` in `main.cpp`, OR call `xy.setInvertX(true)` and `xy.setInvertY(true)` — experiment.
- Head moves backwards along X → `xy.setInvertX(true)`.
- Only one motor moves → wiring issue; test each motor in isolation with the existing `StepperMotor` API first.

- [ ] **Step 2: Pure-Y move test**

Replace with:

```cpp
    xy.moveTo(0, 500);
```

Upload, observe.

**Expected:** both motors step 500 times in **opposite** directions; head moves perpendicular to Step 1.

**Failure modes:**
- Head moves backwards along Y → `xy.setInvertY(true)`.
- Motors step in the same direction instead of opposite → one of the belts is routed incorrectly, OR one motor is mounted backwards. This is a mechanical issue, not something software can fix; swap one motor's wiring polarity at the driver.

- [ ] **Step 3: Diagonal move test**

Replace with:

```cpp
    xy.moveTo(500, 500);
```

Upload, observe.

**Expected:** motor A steps 1000 times, motor B steps 0 times. Head moves diagonally (45°).

- [ ] **Step 4: Square demo (restore Task 6 `main.cpp`)**

Restore `main.cpp` to the full square demo from Task 6. Upload.

**Expected:** head traces a square and returns to its starting point. Add a piece of tape or a marker to verify the loop closes to within a step or two.

- [ ] **Step 5: Bounds refusal test**

Temporarily add right after `xy.setHome();` in `setup()`:

```cpp
    xy.setMaxBounds(500, 500);
    xy.moveTo(1000, 0);   // should be refused
    Serial.printf("  after refused move, at (%ld, %ld)\n", xy.getX(), xy.getY());
```

(And comment out the square demo for this test.)

Upload, observe serial monitor.

**Expected serial output includes:**

```
[CoreXY] refused: target (1000, 0) out of bounds
  after refused move, at (0, 0)
```

**Physical expectation:** head does NOT move. Position stays at (0, 0).

- [ ] **Step 6: Restore the square demo**

Undo the changes from Step 5 so `main.cpp` matches the final Task 6 version. Upload once more to confirm everything still works.

---

## Done

At this point you should have:

- A working `StepperMotor::stepOnce()` primitive.
- A complete `CoreXY` class with manual homing, soft bounds, software direction inversion, and straight-line blocking motion.
- A demo `main.cpp` that draws a square and prints progress over serial.
- Validated each primitive motion (X-only, Y-only, diagonal, square, bounds refusal) on the rig.

If any direction flags (`setInvertX` / `setInvertY`) ended up true during validation, bake those calls into `setup()` so the rig comes up correctly every power-cycle.

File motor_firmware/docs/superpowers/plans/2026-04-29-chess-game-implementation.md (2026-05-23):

# Chess Game Class Implementation Plan

> **For agentic workers:** REQUIRED SUB-SKILL: Use superpowers:subagent-driven-development (recommended) or superpowers:executing-plans to implement this plan task-by-task. Steps use checkbox (`- [ ]`) syntax for tracking.

**Goal:** Implement `ChessGame` (board state + rules) and `MovePlanner` (rectilinear path planning + step-by-step execution) as pure C++ classes with no Arduino dependencies, testable via PlatformIO native environment.

**Architecture:** Two decoupled classes share types defined in `ChessTypes.h`. `ChessGame` enforces chess rules and owns board state. `MovePlanner` holds a reference to `ChessGame`, computes rectilinear physical paths, generates step-by-step `Step` queues for `main.cpp` to execute against `CoreXY` and `Electromagnet`.

**Tech Stack:** C++17, PlatformIO native environment, Unity test framework (bundled with PlatformIO)

---

## File Map

| File | Action | Responsibility |
|---|---|---|
| `src/ChessTypes.h` | Create | Shared enums, structs (Piece, Position, Step, PhysicalConfig) |
| `src/ChessGame.h` | Create | ChessGame class declaration |
| `src/ChessGame.cpp` | Create | ChessGame implementation |
| `src/MovePlanner.h` | Create | MovePlanner class declaration |
| `src/MovePlanner.cpp` | Create | MovePlanner implementation |
| `platformio.ini` | Modify | Add `[env:native]` for host-side unit testing |
| `test/test_chess_game/test_chess_game.cpp` | Create | Unit tests for ChessGame |
| `test/test_move_planner/test_move_planner.cpp` | Create | Unit tests for MovePlanner |
| `src/main.cpp` | Modify | Add ChessGame + MovePlanner usage example |

---

## Task 1: Shared Types + Native Test Environment

**Files:**
- Create: `src/ChessTypes.h`
- Modify: `platformio.ini`

- [ ] **Step 1: Create `src/ChessTypes.h`**

```cpp
#pragma once
#include <cstdint>

enum PieceType  : uint8_t { NONE, PAWN, ROOK, KNIGHT, BISHOP, QUEEN, KING };
enum PieceColor : uint8_t { NO_COLOR, WHITE, BLACK };

struct Piece {
    PieceType  type  = NONE;
    PieceColor color = NO_COLOR;
};

struct Position {
    char col = 'A';  // 'A'–'H'
    int  row = 1;    // 1–8
    bool operator==(const Position& o) const { return col == o.col && row == o.row; }
    bool operator!=(const Position& o) const { return !(*this == o); }
};

struct PhysicalConfig {
    float originX = 3.8f;   // physical X of A-file in cm
    float originY = 5.5f;   // physical Y of rank 1 in cm
    float stepX   = 5.0f;   // cm per file
    float stepY   = 5.0f;   // cm per rank
};

enum  StepType { MOVE_TO, MAGNET_ON, MAGNET_OFF };

struct Step {
    StepType type   = MOVE_TO;
    Position target = {};    // chess square (meaningful for on-board MOVE_TO)
    float    x      = 0.0f; // physical X in cm (authoritative for all MOVE_TO)
    float    y      = 0.0f; // physical Y in cm (authoritative for all MOVE_TO)
    // x and y are 0 for MAGNET_ON / MAGNET_OFF steps
};
```

- [ ] **Step 2: Add native test environment to `platformio.ini`**

```ini
[env:seeed_xiao_esp32s3]
platform = espressif32
board = seeed_xiao_esp32s3
framework = arduino
lib_deps = adafruit/Adafruit VEML7700 Library@^2.1.6

[env:native]
platform = native
```

- [ ] **Step 3: Verify it compiles (no test yet — just confirm headers parse)**

```bash
pio run -e native
```

Expected: BUILD SUCCESS (nothing to compile yet, just checks environment).

- [ ] **Step 4: Commit**

```bash
git add src/ChessTypes.h platformio.ini
git commit -m "feat: add ChessTypes header and native test env"
```

---

## Task 2: ChessGame — Board Initialisation

**Files:**
- Create: `src/ChessGame.h`
- Create: `src/ChessGame.cpp`
- Create: `test/test_chess_game/test_chess_game.cpp`

- [ ] **Step 1: Write the failing tests**

Create `test/test_chess_game/test_chess_game.cpp`:

```cpp
#include <unity.h>
#include "../../src/ChessGame.h"

void setUp()    {}
void tearDown() {}

// ── Standard init ──────────────────────────────────────────────
void test_standard_white_pawn_row2() {
    ChessGame g;
    Piece p = g.getPieceAt({'E', 2});
    TEST_ASSERT_EQUAL(PAWN,  p.type);
    TEST_ASSERT_EQUAL(WHITE, p.color);
}

void test_standard_black_pawn_row7() {
    ChessGame g;
    Piece p = g.getPieceAt({'D', 7});
    TEST_ASSERT_EQUAL(PAWN,  p.type);
    TEST_ASSERT_EQUAL(BLACK, p.color);
}

void test_standard_white_king_e1() {
    ChessGame g;
    Piece p = g.getPieceAt({'E', 1});
    TEST_ASSERT_EQUAL(KING,  p.type);
    TEST_ASSERT_EQUAL(WHITE, p.color);
}

void test_standard_empty_e4() {
    ChessGame g;
    TEST_ASSERT_TRUE(g.isEmpty({'E', 4}));
}

// ── Custom init ────────────────────────────────────────────────
void test_custom_board() {
    Piece board[8][8] = {};
    board[0][4] = {KING, WHITE};  // E1
    board[7][4] = {KING, BLACK};  // E8
    ChessGame g(board);
    TEST_ASSERT_EQUAL(KING, g.getPieceAt({'E', 1}).type);
    TEST_ASSERT_EQUAL(KING, g.getPieceAt({'E', 8}).type);
    TEST_ASSERT_TRUE(g.isEmpty({'E', 4}));
}

// ── Reset ──────────────────────────────────────────────────────
void test_reset_restores_standard() {
    Piece board[8][8] = {};
    board[0][4] = {KING, WHITE};
    ChessGame g(board);
    g.reset();
    Piece p = g.getPieceAt({'A', 1});
    TEST_ASSERT_EQUAL(ROOK,  p.type);
    TEST_ASSERT_EQUAL(WHITE, p.color);
}

int main() {
    UNITY_BEGIN();
    RUN_TEST(test_standard_white_pawn_row2);
    RUN_TEST(test_standard_black_pawn_row7);
    RUN_TEST(test_standard_white_king_e1);
    RUN_TEST(test_standard_empty_e4);
    RUN_TEST(test_custom_board);
    RUN_TEST(test_reset_restores_standard);
    return UNITY_END();
}
```

- [ ] **Step 2: Create `src/ChessGame.h`**

```cpp
#pragma once
#include "ChessTypes.h"
#include <vector>

class ChessGame {
public:
    ChessGame();
    explicit ChessGame(const Piece board[8][8]);
    void reset();

    bool       isLegalMove(Position from, Position to) const;
    bool       applyMove(Position from, Position to);
    PieceColor getTurn()              const;
    Piece      getPieceAt(Position p) const;
    bool       isEmpty(Position p)    const;
    const std::vector<Piece>& getCaptured() const;

private:
    Piece      _board[8][8];   // [rowIdx 0–7][colIdx 0–7]
    PieceColor _turn = WHITE;
    std::vector<Piece> _captured;

    void initStandard();

    bool isPawnMove  (Position from, Position to) const;
    bool isRookMove  (Position from, Position to) const;
    bool isKnightMove(Position from, Position to) const;
    bool isBishopMove(Position from, Position to) const;
    bool isQueenMove (Position from, Position to) const;
    bool isKingMove  (Position from, Position to) const;
    bool isPathClear (Position from, Position to) const;

    static int ci(Position p) { return p.col - 'A'; }
    static int ri(Position p) { return p.row - 1; }

    Piece&       at(Position p)       { return _board[ri(p)][ci(p)]; }
    const Piece& at(Position p) const { return _board[ri(p)][ci(p)]; }
};
```

- [ ] **Step 3: Create `src/ChessGame.cpp` with init only**

```cpp
#include "ChessGame.h"
#include <cstring>

ChessGame::ChessGame() { initStandard(); }

ChessGame::ChessGame(const Piece board[8][8]) {
    memcpy(_board, board, sizeof(_board));
}

void ChessGame::reset() {
    _turn = WHITE;
    _captured.clear();
    initStandard();
}

void ChessGame::initStandard() {
    for (int r = 0; r < 8; r++)
        for (int c = 0; c < 8; c++)
            _board[r][c] = {NONE, NO_COLOR};

    PieceType backRank[] = {ROOK, KNIGHT, BISHOP, QUEEN, KING, BISHOP, KNIGHT, ROOK};
    for (int c = 0; c < 8; c++) {
        _board[0][c] = {backRank[c], WHITE};
        _board[1][c] = {PAWN, WHITE};
        _board[6][c] = {PAWN, BLACK};
        _board[7][c] = {backRank[c], BLACK};
    }
}

PieceColor ChessGame::getTurn()              const { return _turn; }
Piece      ChessGame::getPieceAt(Position p) const { return at(p); }
bool       ChessGame::isEmpty(Position p)    const { return at(p).type == NONE; }
const std::vector<Piece>& ChessGame::getCaptured() const { return _captured; }

// Stubs — will be filled in Tasks 3–6
bool ChessGame::isLegalMove(Position, Position) const { return false; }
bool ChessGame::applyMove(Position, Position)         { return false; }
bool ChessGame::isPawnMove  (Position, Position) const { return false; }
bool ChessGame::isRookMove  (Position, Position) const { return false; }
bool ChessGame::isKnightMove(Position, Position) const { return false; }
bool ChessGame::isBishopMove(Position, Position) const { return false; }
bool ChessGame::isQueenMove (Position, Position) const { return false; }
bool ChessGame::isKingMove  (Position, Position) const { return false; }
bool ChessGame::isPathClear (Position, Position) const { return false; }
```

- [ ] **Step 4: Run tests — verify they pass**

```bash
pio test -e native -f test_chess_game -v
```

Expected: 6 tests PASS.

- [ ] **Step 5: Commit**

```bash
git add src/ChessGame.h src/ChessGame.cpp test/test_chess_game/test_chess_game.cpp
git commit -m "feat: ChessGame board init, custom board, reset"
```

---

## Task 3: ChessGame — Pawn Move Validation (TDD)

**Files:**
- Modify: `test/test_chess_game/test_chess_game.cpp`
- Modify: `src/ChessGame.cpp`

- [ ] **Step 1: Add pawn tests to `test_chess_game.cpp`**

Add these test functions and register them in `main()`:

```cpp
// ── Pawn moves ─────────────────────────────────────────────────
void test_pawn_forward_one() {
    ChessGame g;
    TEST_ASSERT_TRUE(g.isLegalMove({'E', 2}, {'E', 3}));
}

void test_pawn_forward_two_from_start() {
    ChessGame g;
    TEST_ASSERT_TRUE(g.isLegalMove({'E', 2}, {'E', 4}));
}

void test_pawn_forward_two_blocked_by_piece_at_e3() {
    Piece board[8][8] = {};
    board[1][4] = {PAWN, WHITE};   // E2
    board[2][4] = {PAWN, BLACK};   // E3 — blocker
    ChessGame g(board);
    TEST_ASSERT_FALSE(g.isLegalMove({'E', 2}, {'E', 4}));
}

void test_pawn_cannot_go_backward() {
    Piece board[8][8] = {};
    board[2][4] = {PAWN, WHITE};   // E3
    ChessGame g(board);
    TEST_ASSERT_FALSE(g.isLegalMove({'E', 3}, {'E', 2}));
}

void test_pawn_diagonal_capture_legal() {
    Piece board[8][8] = {};
    board[3][4] = {PAWN, WHITE};   // E4
    board[4][3] = {PAWN, BLACK};   // D5 — enemy
    ChessGame g(board);
    TEST_ASSERT_TRUE(g.isLegalMove({'E', 4}, {'D', 5}));
}

void test_pawn_diagonal_no_capture_illegal() {
    ChessGame g;   // D3 is empty
    TEST_ASSERT_FALSE(g.isLegalMove({'E', 2}, {'D', 3}));
}

void test_pawn_cannot_capture_forward() {
    Piece board[8][8] = {};
    board[1][4] = {PAWN, WHITE};   // E2
    board[2][4] = {PAWN, BLACK};   // E3 — blocked
    ChessGame g(board);
    TEST_ASSERT_FALSE(g.isLegalMove({'E', 2}, {'E', 3}));
}
```

In `main()` add:
```cpp
RUN_TEST(test_pawn_forward_one);
RUN_TEST(test_pawn_forward_two_from_start);
RUN_TEST(test_pawn_forward_two_blocked_by_piece_at_e3);
RUN_TEST(test_pawn_cannot_go_backward);
RUN_TEST(test_pawn_diagonal_capture_legal);
RUN_TEST(test_pawn_diagonal_no_capture_illegal);
RUN_TEST(test_pawn_cannot_capture_forward);
```

- [ ] **Step 2: Run to confirm failures**

```bash
pio test -e native -f test_chess_game -v
```

Expected: new pawn tests FAIL (isLegalMove always returns false).

- [ ] **Step 3: Implement `isLegalMove` and `isPawnMove` in `ChessGame.cpp`**

Replace the stubs:

```cpp
bool ChessGame::isLegalMove(Position from, Position to) const {
    if (from.col < 'A' || from.col > 'H' || from.row < 1 || from.row > 8) return false;
    if (to.col   < 'A' || to.col   > 'H' || to.row   < 1 || to.row   > 8) return false;
    if (from == to) return false;
    const Piece& mover = at(from);
    if (mover.type == NONE)           return false;
    if (mover.color != _turn)         return false;
    if (!isEmpty(to) && at(to).color == mover.color) return false;
    switch (mover.type) {
        case PAWN:   return isPawnMove(from, to);
        case ROOK:   return isRookMove(from, to);
        case KNIGHT: return isKnightMove(from, to);
        case BISHOP: return isBishopMove(from, to);
        case QUEEN:  return isQueenMove(from, to);
        case KING:   return isKingMove(from, to);
        default:     return false;
    }
}

bool ChessGame::isPawnMove(Position from, Position to) const {
    int dc  = ci(to) - ci(from);
    int dr  = ri(to) - ri(from);
    int dir = (at(from).color == WHITE) ? 1 : -1;
    int startRi = (at(from).color == WHITE) ? 1 : 6;

    // Forward 1 — destination must be empty
    if (dc == 0 && dr == dir && isEmpty(to)) return true;

    // Forward 2 from starting rank — both squares must be empty
    if (dc == 0 && dr == 2 * dir && ri(from) == startRi) {
        Position mid = {from.col, from.row + dir};
        return isEmpty(mid) && isEmpty(to);
    }

    // Diagonal capture — must be an enemy piece at destination
    if ((dc == 1 || dc == -1) && dr == dir && !isEmpty(to))
        return true;  // friendly-fire already blocked in isLegalMove

    return false;
}
```

- [ ] **Step 4: Run tests — all pass**

```bash
pio test -e native -f test_chess_game -v
```

Expected: 13 tests PASS.

- [ ] **Step 5: Commit**

```bash
git add src/ChessGame.cpp test/test_chess_game/test_chess_game.cpp
git commit -m "feat: pawn move validation"
```

---

## Task 4: ChessGame — Sliding Pieces (Rook, Bishop, Queen)

**Files:**
- Modify: `test/test_chess_game/test_chess_game.cpp`
- Modify: `src/ChessGame.cpp`

- [ ] **Step 1: Add sliding piece tests**

```cpp
// ── Rook ───────────────────────────────────────────────────────
void test_rook_horizontal_clear() {
    Piece board[8][8] = {};
    board[2][0] = {ROOK, WHITE};   // A3
    ChessGame g(board);
    TEST_ASSERT_TRUE(g.isLegalMove({'A', 3}, {'E', 3}));
}

void test_rook_blocked_by_friendly() {
    Piece board[8][8] = {};
    board[2][0] = {ROOK,  WHITE};  // A3
    board[2][2] = {PAWN,  WHITE};  // C3 — friendly blocker
    ChessGame g(board);
    TEST_ASSERT_FALSE(g.isLegalMove({'A', 3}, {'E', 3}));
}

void test_rook_cannot_move_diagonal() {
    Piece board[8][8] = {};
    board[0][0] = {ROOK, WHITE};   // A1
    ChessGame g(board);
    TEST_ASSERT_FALSE(g.isLegalMove({'A', 1}, {'D', 4}));
}

// ── Bishop ─────────────────────────────────────────────────────
void test_bishop_diagonal_clear() {
    Piece board[8][8] = {};
    board[0][2] = {BISHOP, WHITE};  // C1
    ChessGame g(board);
    TEST_ASSERT_TRUE(g.isLegalMove({'C', 1}, {'F', 4}));
}

void test_bishop_blocked() {
    Piece board[8][8] = {};
    board[0][2] = {BISHOP, WHITE};  // C1
    board[1][3] = {PAWN,   WHITE};  // D2 — blocker
    ChessGame g(board);
    TEST_ASSERT_FALSE(g.isLegalMove({'C', 1}, {'F', 4}));
}

void test_bishop_cannot_move_straight() {
    Piece board[8][8] = {};
    board[0][2] = {BISHOP, WHITE};  // C1
    ChessGame g(board);
    TEST_ASSERT_FALSE(g.isLegalMove({'C', 1}, {'C', 4}));
}

// ── Queen ──────────────────────────────────────────────────────
void test_queen_straight_clear() {
    Piece board[8][8] = {};
    board[0][3] = {QUEEN, WHITE};   // D1
    ChessGame g(board);
    TEST_ASSERT_TRUE(g.isLegalMove({'D', 1}, {'D', 5}));
}

void test_queen_diagonal_clear() {
    Piece board[8][8] = {};
    board[0][3] = {QUEEN, WHITE};   // D1
    ChessGame g(board);
    TEST_ASSERT_TRUE(g.isLegalMove({'D', 1}, {'G', 4}));
}
```

Add all 8 to `main()` with `RUN_TEST(...)`.

- [ ] **Step 2: Run to confirm failures**

```bash
pio test -e native -f test_chess_game -v
```

Expected: new sliding piece tests FAIL.

- [ ] **Step 3: Implement `isPathClear`, `isRookMove`, `isBishopMove`, `isQueenMove`**

```cpp
bool ChessGame::isPathClear(Position from, Position to) const {
    int dc = ci(to) - ci(from);
    int dr = ri(to) - ri(from);
    int stepC = (dc == 0) ? 0 : (dc > 0 ? 1 : -1);
    int stepR = (dr == 0) ? 0 : (dr > 0 ? 1 : -1);
    int c = ci(from) + stepC;
    int r = ri(from) + stepR;
    while (c != ci(to) || r != ri(to)) {
        if (_board[r][c].type != NONE) return false;
        c += stepC;
        r += stepR;
    }
    return true;
}

bool ChessGame::isRookMove(Position from, Position to) const {
    int dc = ci(to) - ci(from);
    int dr = ri(to) - ri(from);
    if (dc != 0 && dr != 0) return false;
    return isPathClear(from, to);
}

bool ChessGame::isBishopMove(Position from, Position to) const {
    int dc = ci(to) - ci(from);
    int dr = ri(to) - ri(from);
    if (dc < 0) dc = -dc;
    if (dr < 0) dr = -dr;
    if (dc != dr) return false;
    return isPathClear(from, to);
}

bool ChessGame::isQueenMove(Position from, Position to) const {
    return isRookMove(from, to) || isBishopMove(from, to);
}
```

- [ ] **Step 4: Run tests — all pass**

```bash
pio test -e native -f test_chess_game -v
```

Expected: 21 tests PASS.

- [ ] **Step 5: Commit**

```bash
git add src/ChessGame.cpp test/test_chess_game/test_chess_game.cpp
git commit -m "feat: rook, bishop, queen move validation"
```

---

## Task 5: ChessGame — Knight and King

**Files:**
- Modify: `test/test_chess_game/test_chess_game.cpp`
- Modify: `src/ChessGame.cpp`

- [ ] **Step 1: Add knight and king tests**

```cpp
// ── Knight ─────────────────────────────────────────────────────
void test_knight_l_shape() {
    Piece board[8][8] = {};
    board[0][1] = {KNIGHT, WHITE};   // B1
    ChessGame g(board);
    TEST_ASSERT_TRUE(g.isLegalMove({'B', 1}, {'C', 3}));
    TEST_ASSERT_TRUE(g.isLegalMove({'B', 1}, {'A', 3}));
    TEST_ASSERT_TRUE(g.isLegalMove({'B', 1}, {'D', 2}));
}

void test_knight_jumps_over_pieces() {
    ChessGame g;  // B1 knight surrounded by pawns — can still jump
    TEST_ASSERT_TRUE(g.isLegalMove({'B', 1}, {'C', 3}));
}

void test_knight_invalid_move() {
    Piece board[8][8] = {};
    board[0][1] = {KNIGHT, WHITE};   // B1
    ChessGame g(board);
    TEST_ASSERT_FALSE(g.isLegalMove({'B', 1}, {'B', 3}));
}

// ── King ───────────────────────────────────────────────────────
void test_king_one_step_any_direction() {
    Piece board[8][8] = {};
    board[3][4] = {KING, WHITE};   // E4
    ChessGame g(board);
    TEST_ASSERT_TRUE(g.isLegalMove({'E', 4}, {'E', 5}));
    TEST_ASSERT_TRUE(g.isLegalMove({'E', 4}, {'D', 4}));
    TEST_ASSERT_TRUE(g.isLegalMove({'E', 4}, {'F', 3}));
}

void test_king_cannot_move_two_squares() {
    Piece board[8][8] = {};
    board[3][4] = {KING, WHITE};   // E4
    ChessGame g(board);
    TEST_ASSERT_FALSE(g.isLegalMove({'E', 4}, {'E', 6}));
}
```

Add 5 tests to `main()`.

- [ ] **Step 2: Run to confirm failures**

```bash
pio test -e native -f test_chess_game -v
```

Expected: new knight/king tests FAIL.

- [ ] **Step 3: Implement `isKnightMove` and `isKingMove`**

```cpp
bool ChessGame::isKnightMove(Position from, Position to) const {
    int dc = ci(to) - ci(from);  if (dc < 0) dc = -dc;
    int dr = ri(to) - ri(from);  if (dr < 0) dr = -dr;
    return (dc == 1 && dr == 2) || (dc == 2 && dr == 1);
}

bool ChessGame::isKingMove(Position from, Position to) const {
    int dc = ci(to) - ci(from);  if (dc < 0) dc = -dc;
    int dr = ri(to) - ri(from);  if (dr < 0) dr = -dr;
    return dc <= 1 && dr <= 1;
}
```

- [ ] **Step 4: Run tests — all pass**

```bash
pio test -e native -f test_chess_game -v
```

Expected: 26 tests PASS.

- [ ] **Step 5: Commit**

```bash
git add src/ChessGame.cpp test/test_chess_game/test_chess_game.cpp
git commit -m "feat: knight and king move validation"
```

---

## Task 6: ChessGame — Turn Validation, `applyMove`, Capture Tracking

**Files:**
- Modify: `test/test_chess_game/test_chess_game.cpp`
- Modify: `src/ChessGame.cpp`

- [ ] **Step 1: Add tests**

```cpp
// ── Turn validation ────────────────────────────────────────────
void test_black_cannot_move_on_whites_turn() {
    ChessGame g;
    TEST_ASSERT_FALSE(g.isLegalMove({'E', 7}, {'E', 6}));  // black pawn, white's turn
}

// ── applyMove ──────────────────────────────────────────────────
void test_apply_move_updates_board() {
    ChessGame g;
    g.applyMove({'E', 2}, {'E', 4});
    TEST_ASSERT_TRUE(g.isEmpty({'E', 2}));
    Piece p = g.getPieceAt({'E', 4});
    TEST_ASSERT_EQUAL(PAWN,  p.type);
    TEST_ASSERT_EQUAL(WHITE, p.color);
}

void test_apply_move_alternates_turn() {
    ChessGame g;
    TEST_ASSERT_EQUAL(WHITE, g.getTurn());
    g.applyMove({'E', 2}, {'E', 4});
    TEST_ASSERT_EQUAL(BLACK, g.getTurn());
}

void test_apply_move_capture_adds_to_captured() {
    Piece board[8][8] = {};
    board[3][4] = {PAWN, WHITE};  // E4
    board[4][3] = {PAWN, BLACK};  // D5 — enemy
    ChessGame g(board);
    g.applyMove({'E', 4}, {'D', 5});
    TEST_ASSERT_EQUAL(1u, g.getCaptured().size());
    TEST_ASSERT_EQUAL(BLACK, g.getCaptured()[0].color);
}

void test_apply_move_illegal_returns_false() {
    ChessGame g;
    TEST_ASSERT_FALSE(g.applyMove({'E', 2}, {'E', 5}));  // too far for pawn
}
```

Add 5 tests to `main()`.

- [ ] **Step 2: Run to confirm failures**

```bash
pio test -e native -f test_chess_game -v
```

Expected: new turn/apply tests FAIL.

- [ ] **Step 3: Implement `applyMove`**

```cpp
bool ChessGame::applyMove(Position from, Position to) {
    if (!isLegalMove(from, to)) return false;
    if (!isEmpty(to)) _captured.push_back(at(to));
    at(to)   = at(from);
    at(from) = {NONE, NO_COLOR};
    _turn    = (_turn == WHITE) ? BLACK : WHITE;
    return true;
}
```

- [ ] **Step 4: Run tests — all pass**

```bash
pio test -e native -f test_chess_game -v
```

Expected: 31 tests PASS.

- [ ] **Step 5: Commit**

```bash
git add src/ChessGame.cpp test/test_chess_game/test_chess_game.cpp
git commit -m "feat: applyMove, turn alternation, capture tracking"
```

---

## Task 7: MovePlanner — Setup + Coordinate Mapping

**Files:**
- Create: `src/MovePlanner.h`
- Create: `src/MovePlanner.cpp`
- Create: `test/test_move_planner/test_move_planner.cpp`

- [ ] **Step 1: Create `src/MovePlanner.h`**

```cpp
#pragma once
#include "ChessTypes.h"
#include "ChessGame.h"
#include <queue>
#include <vector>
#include <utility>

class MovePlanner {
public:
    MovePlanner(ChessGame& game, PhysicalConfig config);

    bool startMove(Position from, Position to);
    bool nextStep();
    bool isMoveDone() const;
    Step peekNextStep() const;

private:
    ChessGame&     _game;
    PhysicalConfig _cfg;
    std::queue<Step> _steps;

    Position _pendingFrom = {};
    Position _pendingTo   = {};
    bool     _hasPending  = false;

    // Pre-computed border parking slots for captured pieces (physical XY pairs)
    std::vector<std::pair<float, float>> _capturedSlots;
    int _nextSlot = 0;

    void initCapturedSlots();

    // Path planning helpers
    std::vector<Position> rectilinearPath(Position from, Position to) const;
    Position findParkSquare(Position blocked, const Piece planBoard[8][8]) const;
    void appendPickAndPlace(Position from, Position to);
    void appendCaptureParkXY(Position capturedAt, float px, float py);
    void copyGameBoard(Piece out[8][8]) const;

    float physX(Position p) const;
    float physY(Position p) const;
    Step  moveStep(Position p) const;
    Step  moveStepXY(float x, float y) const;
};
```

- [ ] **Step 2: Create `src/MovePlanner.cpp` (coordinate mapping + init only)**

```cpp
#include "MovePlanner.h"
#include <cstring>

MovePlanner::MovePlanner(ChessGame& game, PhysicalConfig config)
    : _game(game), _cfg(config) {
    initCapturedSlots();
}

// Pre-generate 24 border parking slots (8 bottom, 8 top, 8 right)
void MovePlanner::initCapturedSlots() {
    float margin = _cfg.stepY * 0.5f;
    float yBottom = _cfg.originY - margin;
    float yTop    = _cfg.originY + 7.0f * _cfg.stepY + margin;
    float xRight  = _cfg.originX + 7.0f * _cfg.stepX + _cfg.stepX * 0.5f;

    for (int c = 0; c < 8; c++)
        _capturedSlots.push_back({_cfg.originX + c * _cfg.stepX, yBottom});
    for (int c = 0; c < 8; c++)
        _capturedSlots.push_back({_cfg.originX + c * _cfg.stepX, yTop});
    for (int r = 0; r < 8; r++)
        _capturedSlots.push_back({xRight, _cfg.originY + r * _cfg.stepY});
}

float MovePlanner::physX(Position p) const {
    return _cfg.originX + (p.col - 'A') * _cfg.stepX;
}
float MovePlanner::physY(Position p) const {
    return _cfg.originY + (p.row - 1)   * _cfg.stepY;
}

Step MovePlanner::moveStep(Position p) const {
    return {MOVE_TO, p, physX(p), physY(p)};
}
Step MovePlanner::moveStepXY(float x, float y) const {
    return {MOVE_TO, {'Z', 0}, x, y};
}

void MovePlanner::copyGameBoard(Piece out[8][8]) const {
    for (int r = 0; r < 8; r++)
        for (int c = 0; c < 8; c++)
            out[r][c] = _game.getPieceAt({(char)('A' + c), r + 1});
}

// Stubs — implemented in Tasks 8–11
bool MovePlanner::startMove(Position, Position)  { return false; }
bool MovePlanner::nextStep()                     { return false; }
bool MovePlanner::isMoveDone()             const { return true; }
Step MovePlanner::peekNextStep()           const { return {}; }

std::vector<Position> MovePlanner::rectilinearPath(Position, Position) const { return {}; }
Position MovePlanner::findParkSquare(Position b, const Piece[8][8]) const { return b; }
void MovePlanner::appendPickAndPlace(Position, Position) {}
void MovePlanner::appendCaptureParkXY(Position, float, float) {}
```

- [ ] **Step 3: Create `test/test_move_planner/test_move_planner.cpp` with coordinate test**

```cpp
#include <unity.h>
#include "../../src/MovePlanner.h"

void setUp()    {}
void tearDown() {}

static ChessGame makeMinimalGame(Position whitePiecePos, PieceType type) {
    Piece board[8][8] = {};
    board[whitePiecePos.row - 1][whitePiecePos.col - 'A'] = {type, WHITE};
    return ChessGame(board);
}

void test_phys_coords_a1() {
    Piece board[8][8] = {};
    board[0][0] = {ROOK, WHITE};   // A1
    ChessGame g(board);
    MovePlanner p(g, {3.8f, 5.5f, 5.0f, 5.0f});
    // Verify by checking the step x/y after a single-square move
    // A1 → A2: MOVE_TO A1 step should have x=3.8, y=5.5
    // We can't call startMove yet, so just verify init doesn't crash
    TEST_ASSERT_FALSE(p.isMoveDone() == false);   // isMoveDone() == true (queue empty)
    TEST_ASSERT_TRUE(p.isMoveDone());
}

int main() {
    UNITY_BEGIN();
    RUN_TEST(test_phys_coords_a1);
    return UNITY_END();
}
```

- [ ] **Step 4: Run both test suites**

```bash
pio test -e native -v
```

Expected: 32 total tests PASS.

- [ ] **Step 5: Commit**

```bash
git add src/MovePlanner.h src/MovePlanner.cpp test/test_move_planner/test_move_planner.cpp
git commit -m "feat: MovePlanner skeleton, coordinate mapping, border slot init"
```

---

## Task 8: MovePlanner — Simple Move (No Obstacles)

**Files:**
- Modify: `test/test_move_planner/test_move_planner.cpp`
- Modify: `src/MovePlanner.cpp`

- [ ] **Step 1: Add step-sequence tests**

```cpp
// Helper: drain queue into a vector for inspection
static std::vector<Step> drainSteps(MovePlanner& p) {
    std::vector<Step> steps;
    while (!p.isMoveDone()) {
        steps.push_back(p.peekNextStep());
        p.nextStep();
    }
    return steps;
}

void test_simple_vertical_move_step_count() {
    // E2 → E4: MOVE_TO E2, MAGNET_ON, MOVE_TO E3, MOVE_TO E4, MAGNET_OFF = 5 steps
    Piece board[8][8] = {};
    board[1][4] = {PAWN, WHITE};  // E2
    ChessGame g(board);
    MovePlanner p(g, {3.8f, 5.5f, 5.0f, 5.0f});
    TEST_ASSERT_TRUE(p.startMove({'E', 2}, {'E', 4}));
    auto steps = drainSteps(p);
    TEST_ASSERT_EQUAL(5u, steps.size());
}

void test_simple_move_step_sequence() {
    Piece board[8][8] = {};
    board[1][4] = {PAWN, WHITE};  // E2
    ChessGame g(board);
    MovePlanner p(g, {3.8f, 5.5f, 5.0f, 5.0f});
    p.startMove({'E', 2}, {'E', 4});

    // Step 0: MOVE_TO E2
    Step s = p.peekNextStep();
    TEST_ASSERT_EQUAL(MOVE_TO, s.type);
    TEST_ASSERT_EQUAL('E', s.target.col);
    TEST_ASSERT_EQUAL(2,   s.target.row);
    p.nextStep();

    // Step 1: MAGNET_ON
    s = p.peekNextStep();
    TEST_ASSERT_EQUAL(MAGNET_ON, s.type);
    p.nextStep();

    // Step 2: MOVE_TO E3 (intermediate)
    s = p.peekNextStep();
    TEST_ASSERT_EQUAL(MOVE_TO, s.type);
    TEST_ASSERT_EQUAL(3, s.target.row);
    p.nextStep();

    // Step 3: MOVE_TO E4
    s = p.peekNextStep();
    TEST_ASSERT_EQUAL(MOVE_TO, s.type);
    TEST_ASSERT_EQUAL(4, s.target.row);
    p.nextStep();

    // Step 4: MAGNET_OFF
    s = p.peekNextStep();
    TEST_ASSERT_EQUAL(MAGNET_OFF, s.type);
    p.nextStep();

    TEST_ASSERT_TRUE(p.isMoveDone());
}

void test_illegal_move_rejected() {
    ChessGame g;
    MovePlanner p(g, {3.8f, 5.5f, 5.0f, 5.0f});
    TEST_ASSERT_FALSE(p.startMove({'E', 2}, {'E', 5}));  // pawn can't jump 3
    TEST_ASSERT_TRUE(p.isMoveDone());  // queue stays empty
}

void test_phys_x_y_in_step() {
    Piece board[8][8] = {};
    board[1][4] = {PAWN, WHITE};  // E2
    ChessGame g(board);
    MovePlanner p(g, {3.8f, 5.5f, 5.0f, 5.0f});
    p.startMove({'E', 2}, {'E', 4});
    Step s = p.peekNextStep();
    // E = col index 4 → x = 3.8 + 4*5.0 = 23.8
    TEST_ASSERT_FLOAT_WITHIN(0.001f, 23.8f, s.x);
    // row 2 → y = 5.5 + 1*5.0 = 10.5
    TEST_ASSERT_FLOAT_WITHIN(0.001f, 10.5f, s.y);
}
```

Add 4 tests to `main()`.

- [ ] **Step 2: Run to confirm failures**

```bash
pio test -e native -f test_move_planner -v
```

Expected: new tests FAIL.

- [ ] **Step 3: Implement `rectilinearPath`, `appendPickAndPlace`, `startMove` (no-obstacle case)**

```cpp
// Returns intermediate squares between from and to, horizontal leg first.
// Does NOT include from or to themselves.
std::vector<Position> MovePlanner::rectilinearPath(Position from, Position to) const {
    std::vector<Position> path;
    int fc = from.col - 'A', fr = from.row - 1;
    int tc = to.col   - 'A', tr = to.row   - 1;
    int stepC = (tc > fc) ? 1 : (tc < fc ? -1 : 0);
    int stepR = (tr > fr) ? 1 : (tr < fr ? -1 : 0);

    // Horizontal leg
    for (int c = fc + stepC; c != tc; c += stepC)
        path.push_back({(char)('A' + c), from.row});

    // Corner square (only for L-shaped paths)
    if (fc != tc && fr != tr)
        path.push_back({to.col, from.row});

    // Vertical leg
    for (int r = fr + stepR; r != tr; r += stepR)
        path.push_back({to.col, r + 1});

    return path;
}

void MovePlanner::appendPickAndPlace(Position from, Position to) {
    _steps.push(moveStep(from));
    _steps.push({MAGNET_ON, from, 0.0f, 0.0f});
    for (auto& sq : rectilinearPath(from, to))
        _steps.push(moveStep(sq));
    _steps.push(moveStep(to));
    _steps.push({MAGNET_OFF, to, 0.0f, 0.0f});
}

void MovePlanner::appendCaptureParkXY(Position capturedAt, float px, float py) {
    _steps.push(moveStep(capturedAt));
    _steps.push({MAGNET_ON, capturedAt, 0.0f, 0.0f});
    _steps.push(moveStepXY(px, py));
    _steps.push({MAGNET_OFF, {'Z', 0}, 0.0f, 0.0f});
}

bool MovePlanner::startMove(Position from, Position to) {
    if (!_game.isLegalMove(from, to)) return false;
    while (!_steps.empty()) _steps.pop();
    _pendingFrom = from;
    _pendingTo   = to;
    _hasPending  = true;

    Piece planBoard[8][8];
    copyGameBoard(planBoard);

    auto pathSquares = rectilinearPath(from, to);

    // If destination occupied (capture), park it first
    if (!_game.isEmpty(to)) {
        if (_nextSlot < (int)_capturedSlots.size()) {
            auto [px, py] = _capturedSlots[_nextSlot++];
            appendCaptureParkXY(to, px, py);
            planBoard[to.row - 1][to.col - 'A'] = {NONE, NO_COLOR};
        }
    }

    // Displace blockers along path
    std::vector<std::pair<Position, Position>> displacements;
    for (auto& sq : pathSquares) {
        if (planBoard[sq.row - 1][sq.col - 'A'].type != NONE) {
            Position park = findParkSquare(sq, planBoard);
            appendPickAndPlace(sq, park);
            planBoard[park.row - 1][park.col - 'A'] = planBoard[sq.row - 1][sq.col - 'A'];
            planBoard[sq.row - 1][sq.col - 'A']     = {NONE, NO_COLOR};
            displacements.push_back({sq, park});
        }
    }

    // Main piece move
    appendPickAndPlace(from, to);

    // Restore blockers in reverse
    for (int i = (int)displacements.size() - 1; i >= 0; i--)
        appendPickAndPlace(displacements[i].second, displacements[i].first);

    return true;
}

bool MovePlanner::isMoveDone() const { return _steps.empty(); }

Step MovePlanner::peekNextStep() const {
    if (_steps.empty()) return {};
    return _steps.front();
}

bool MovePlanner::nextStep() {
    if (_steps.empty()) return false;
    _steps.pop();
    if (_steps.empty() && _hasPending) {
        _game.applyMove(_pendingFrom, _pendingTo);
        _hasPending = false;
    }
    return !_steps.empty();
}
```

- [ ] **Step 4: Implement `findParkSquare`**

```cpp
Position MovePlanner::findParkSquare(Position blocked, const Piece planBoard[8][8]) const {
    int ci = blocked.col - 'A';
    int ri = blocked.row - 1;
    // Search orthogonal neighbors: up, down, right, left
    const int dcs[] = { 0,  0, 1, -1};
    const int drs[] = { 1, -1, 0,  0};
    for (int i = 0; i < 4; i++) {
        int nc = ci + dcs[i];
        int nr = ri + drs[i];
        if (nc >= 0 && nc < 8 && nr >= 0 && nr < 8) {
            if (planBoard[nr][nc].type == NONE)
                return {(char)('A' + nc), nr + 1};
        }
    }
    return blocked;  // fallback: all neighbors occupied (shouldn't happen in normal play)
}
```

- [ ] **Step 5: Run all tests — all pass**

```bash
pio test -e native -v
```

Expected: 36 total tests PASS.

- [ ] **Step 6: Commit**

```bash
git add src/MovePlanner.cpp test/test_move_planner/test_move_planner.cpp
git commit -m "feat: MovePlanner simple move path planning and step execution"
```

---

## Task 9: MovePlanner — Obstacle Displacement

**Files:**
- Modify: `test/test_move_planner/test_move_planner.cpp`

- [ ] **Step 1: Add obstacle displacement tests**

```cpp
void test_blocker_displaced_and_restored() {
    // E2 (white pawn) → E4, but E3 has a white rook blocking
    Piece board[8][8] = {};
    board[1][4] = {PAWN, WHITE};   // E2
    board[2][4] = {ROOK, WHITE};   // E3 — blocker
    ChessGame g(board);
    MovePlanner p(g, {3.8f, 5.5f, 5.0f, 5.0f});
    TEST_ASSERT_TRUE(p.startMove({'E', 2}, {'E', 4}));

    auto steps = drainSteps(p);

    // Expect: [displace E3 rook] + [move E2 pawn to E4] + [restore E3 rook]
    // Each pick-and-place for adjacent square = MOVE_TO + MAGNET_ON + MOVE_TO + MAGNET_OFF = 4 steps
    // E3 → park (adjacent, 1 sq): 4 steps
    // E2 → E4 (2 intermediate: E3): 5 steps
    // park → E3: 4 steps
    // Total = 13
    TEST_ASSERT_EQUAL(13u, steps.size());
    // First step must be MOVE_TO E3 (pick up blocker first)
    TEST_ASSERT_EQUAL(MOVE_TO, steps[0].type);
    TEST_ASSERT_EQUAL(3, steps[0].target.row);
    TEST_ASSERT_EQUAL('E', steps[0].target.col);
}

void test_board_state_after_blocked_move() {
    Piece board[8][8] = {};
    board[1][4] = {PAWN, WHITE};   // E2
    board[2][4] = {ROOK, WHITE};   // E3 — blocker
    ChessGame g(board);
    MovePlanner p(g, {3.8f, 5.5f, 5.0f, 5.0f});
    p.startMove({'E', 2}, {'E', 4});
    drainSteps(p);  // executes all steps; applyMove called at end
    // After move: E2 empty, E4 has pawn, E3 has rook (restored)
    TEST_ASSERT_TRUE(g.isEmpty({'E', 2}));
    TEST_ASSERT_EQUAL(PAWN, g.getPieceAt({'E', 4}).type);
    TEST_ASSERT_EQUAL(ROOK, g.getPieceAt({'E', 3}).type);
}
```

Add 2 tests to `main()`.

- [ ] **Step 2: Run — both pass** (implementation already handles this in Task 8)

```bash
pio test -e native -f test_move_planner -v
```

Expected: all tests PASS including the 2 new ones.

- [ ] **Step 3: Commit**

```bash
git add test/test_move_planner/test_move_planner.cpp
git commit -m "test: MovePlanner obstacle displacement verification"
```

---

## Task 10: MovePlanner — Capture and Border Parking

**Files:**
- Modify: `test/test_move_planner/test_move_planner.cpp`

- [ ] **Step 1: Add capture tests**

```cpp
void test_capture_step_goes_to_border() {
    // White pawn at E4 captures black pawn at D5
    Piece board[8][8] = {};
    board[3][4] = {PAWN, WHITE};   // E4
    board[4][3] = {PAWN, BLACK};   // D5
    ChessGame g(board);
    MovePlanner p(g, {3.8f, 5.5f, 5.0f, 5.0f});
    TEST_ASSERT_TRUE(p.startMove({'E', 4}, {'D', 5}));

    auto steps = drainSteps(p);

    // Capture park sequence: MOVE_TO D5, MAGNET_ON, MOVE_TO border (XY), MAGNET_OFF = 4 steps
    // Main move E4 → D5 (L-shape, 1 corner): MOVE_TO E4, MAGNET_ON, MOVE_TO D4 (corner), MOVE_TO D5, MAGNET_OFF = 5 steps
    // Total = 9 steps
    TEST_ASSERT_EQUAL(9u, steps.size());

    // Step 0: MOVE_TO D5 (picking up captured piece first)
    TEST_ASSERT_EQUAL(MOVE_TO, steps[0].type);
    TEST_ASSERT_EQUAL('D', steps[0].target.col);
    TEST_ASSERT_EQUAL(5,   steps[0].target.row);

    // Step 2: MOVE_TO border (off-board coords, target col == 'Z')
    TEST_ASSERT_EQUAL(MOVE_TO, steps[2].type);
    TEST_ASSERT_EQUAL('Z', steps[2].target.col);
}

void test_capture_updates_board_and_captured_list() {
    Piece board[8][8] = {};
    board[3][4] = {PAWN, WHITE};   // E4
    board[4][3] = {PAWN, BLACK};   // D5
    ChessGame g(board);
    MovePlanner p(g, {3.8f, 5.5f, 5.0f, 5.0f});
    p.startMove({'E', 4}, {'D', 5});
    drainSteps(p);
    TEST_ASSERT_EQUAL(PAWN, g.getPieceAt({'D', 5}).type);
    TEST_ASSERT_EQUAL(WHITE, g.getPieceAt({'D', 5}).color);
    TEST_ASSERT_EQUAL(1u, g.getCaptured().size());
}
```

Add 2 tests to `main()`.

- [ ] **Step 2: Run — both pass** (implementation already handles this in Task 8)

```bash
pio test -e native -f test_move_planner -v
```

Expected: all tests PASS.

- [ ] **Step 3: Commit**

```bash
git add test/test_move_planner/test_move_planner.cpp
git commit -m "test: MovePlanner capture and border parking verification"
```

---

## Task 11: Integration — Update `main.cpp`

**Files:**
- Modify: `src/main.cpp`

- [ ] **Step 1: Add ChessGame and MovePlanner to `main.cpp`**

Replace the entire file content with:

```cpp
#include <Arduino.h>
#include "StepperMotor.h"
#include "CoreXY.h"
#include "Electromagnet.h"
#include "ChessGame.h"
#include "MovePlanner.h"

StepperMotor motorA(D4, D5, D6);
StepperMotor motorB(D9, D8, D7);
CoreXY       xy(motorA, motorB);
Electromagnet magnet(D2);

static constexpr PhysicalConfig BOARD_CFG = {3.8f, 5.5f, 5.0f, 5.0f};

ChessGame   game;
MovePlanner planner(game, BOARD_CFG);

void setup() {
    Serial.begin(115200);
    delay(1000);

    xy.begin();
    xy.setSpeed(1500);
    xy.setHome();
    xy.setMaxBounds(16400, 16400);
    magnet.begin();

    Serial.println("[Chess] Ready. Enter move as FROM-TO, e.g. E2-E4");
}

void loop() {
    // Execute pending steps
    if (!planner.isMoveDone()) {
        Step s = planner.peekNextStep();
        // TODO: insert hall-effect sensor check here before advancing
        planner.nextStep();
        if      (s.type == MOVE_TO)    xy.moveToCm(s.x, s.y);
        else if (s.type == MAGNET_ON)  magnet.on();
        else if (s.type == MAGNET_OFF) magnet.off();
        return;
    }

    // Parse new move input from Serial (format: "E2-E4")
    if (!Serial.available()) return;
    String input = Serial.readStringUntil('\n');
    input.trim();
    input.toUpperCase();

    if (input.length() < 5 || input.charAt(2) != '-') {
        Serial.println("  Invalid format. Use FROM-TO, e.g. E2-E4");
        return;
    }

    Position from = {input.charAt(0), input.substring(1, 2).toInt()};
    Position to   = {input.charAt(3), input.substring(4).toInt()};

    if (!planner.startMove(from, to)) {
        Serial.printf("  Illegal move: %c%d -> %c%d\n",
                      from.col, from.row, to.col, to.row);
        return;
    }

    Serial.printf("  Moving %c%d -> %c%d\n",
                  from.col, from.row, to.col, to.row);
}
```

- [ ] **Step 2: Build for the target board (verify it compiles)**

```bash
pio run -e seeed_xiao_esp32s3
```

Expected: BUILD SUCCESS.

- [ ] **Step 3: Run native tests one final time**

```bash
pio test -e native -v
```

Expected: all 40 tests PASS.

- [ ] **Step 4: Commit**

```bash
git add src/main.cpp
git commit -m "feat: integrate ChessGame and MovePlanner into main.cpp"
```

---

## Known Limitations (noted for future work)

- Displacement moves to adjacent squares do not recursively check for sub-blockers (safe for adjacent 1-square moves).
- Captured piece path to the border assumes a clear path (no pieces between capture square and board edge).
- No check, checkmate, or stalemate detection.
- No castling, en passant, or pawn promotion.
- Hall effect sensor integration point is in `main.cpp` loop (marked with `TODO` comment).

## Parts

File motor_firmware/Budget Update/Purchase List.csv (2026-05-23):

Order Date | Order ID | Account Group | PO Number | Order Quantity | Currency | Order Subtotal | Order Shipping & Handling | Order Promotion | Order Tax | Order Net Total | Order Status | Approver | Order Receiving Status | Order Received Quantity | Account User | Account User Email | Invoice Status | Total Amount | Invoice Due Amount | Invoice Issue Date | Invoice Due Date | Payment Reference ID | Payment Date | Payment Amount | Payment Instrument Type | Payment Identifier | Amazon-Internal Product Category | ASIN | Title | UNSPSC | Segment | Family | Class | Commodity | Brand Code | Brand | Manufacturer | National Stock Number | Item model number | Part number | Product Condition | Company Compliance | Listed PPU | Purchase PPU | Item Quantity | Item Subtotal | Item Shipping & Handling | Item Promotion | Item Tax | Item Net Total | PO Line Item Id | Tax Exemption Applied | Tax Exemption Type | Tax Exemption Opt Out | Pricing Savings program | Pricing Discount Applied | Receiving Status | Received Quantity | Received Date
04/15/2026 | 111-9716725-0575448 | Team 2 |  | 1 | USD | 7.88 | 0.00 | 0.00 | 0.81 | 8.69 | Closed | GIX PAY |  |  | Youngpyung Lee | yplee9487@gmail.com | N/A | N/A | N/A | N/A | N/A | 3ad1msvjUlnaoTdc8GsW | 04/16/2026 | 8.69 | Visa | ="3832" | Business, Industrial, & Scientific Supplies Basic | B07BPKX47Y | WINSINN GT2 Idler Pulley - 20 Teeth, 5mm Bore, for 10mm Width Timing Belt, Aluminum - Ideal for 3D Printers, CNC Machines (5-Pack) | ="24101600" | Material Handling and Conditioning and Storage Machinery and their Accessories and Supplies | Material handling machinery and equipment | Lifting equipment and accessories | Lifting equipment and accessories |  | WINSINN | WINSINN |  | 10MHL20B5T | 10MHL20B5T | New |  | N/A | 7.88 | 1 | 7.88 | 0.00 |  | 0.81 | 8.69 |  | No |  | No | Quantity Discount | 2.11 |  |  | N/A
04/14/2026 | 111-7810504-0048266 | Team 2 |  | 2 | USD | 25.98 | 0.00 | 0.00 | 2.68 | 28.66 | Closed | GIX PAY |  |  | Youngpyung Lee | yplee9487@gmail.com | N/A | N/A | N/A | N/A | N/A | 1zbNWIQGFFpYF8JTBS7D | 04/15/2026 | 28.66 | Visa | ="3832" | Business, Industrial, & Scientific Supplies Basic | B097T4DFM6 | SeekLiny 3D Print GT2 Open Timing Belt 10 Meters (32.8 Ft) Length 2mm Pitch 10mm Width Rubber Drive Belt for Creality Anycubic Anet Series 3D Printer | ="26111800" | Power Generation and Distribution Machinery and Accessories | Batteries and generators and kinetic power transmission | Drive components | Drive components |  | SeekLiny | SeekLiny |  | SeekLiny-US-Timingbelt10M10mm | SeekLiny-US-Timingbelt10M10mm | New |  | N/A | 16.99 | 1 | 16.99 | 0.00 |  | 1.75 | 18.74 |  | No |  | No | N/A | 0.00 |  |  | N/A
04/14/2026 | 111-7810504-0048266 | Team 2 |  | 2 | USD | 25.98 | 0.00 | 0.00 | 2.68 | 28.66 | Closed | GIX PAY |  |  | Youngpyung Lee | yplee9487@gmail.com | N/A | N/A | N/A | N/A | N/A | 1zbNWIQGFFpYF8JTBS7D | 04/15/2026 | 28.66 | Visa | ="3832" | Business, Industrial, & Scientific Supplies Basic | B0DFWDTSBZ | 260 Pcs M5 Screws Assortment Kit, M5x 8/10/12/16/20/25/30/35mm M5 Bolts Kit 12.9 Alloy Steel Nuts and Bolts Assortment Kit Black Zinc Plated Hex Socket Head Screws Nuts Bolts and Washers Set | ="31162400" | Manufacturing Components and Supplies | Hardware | Miscellaneous fasteners | Miscellaneous fasteners |  | Hapric | Hapric |  | G2647K-11-N | G2647K-11-N | New |  | N/A | 8.99 | 1 | 8.99 | 0.00 |  | 0.93 | 9.92 |  | No |  | No | N/A | 0.00 |  |  | N/A
04/08/2026 | 111-7916563-5386627 | Team 2 |  | 1 | USD | 13.99 | 0.00 | 0.00 | 1.44 | 15.43 | Closed | GIX PAY |  |  | Youngpyung Lee | yplee9487@gmail.com | N/A | N/A | N/A | N/A | N/A | vU75ejAEXwHiRqDzIysl | 04/09/2026 | 15.43 | Visa | ="3832" | Business, Industrial, & Scientific Supplies Basic | B08SMDY3SQ | BIGTREETECH TMC2209 V1.3 UART Stepper Motor Driver 2.8A Peak Stepstick Silent Driver for Manta M8P, Octopus V1.1, Octopus Pro, SKR 3, SKR V1.4 Turbo, SKR Pro V1.2 3D Printer Control Board (2 PCS) | ="26111500" | Power Generation and Distribution Machinery and Accessories | Batteries and generators and kinetic power transmission | Kinetic power transmission | Kinetic power transmission |  | BIGTREETECH | BIGTREETECH |  | KINGPRINT-ZZB000316*2 | KINGPRINT-ZZB000316*2 | New |  | N/A | 13.99 | 1 | 13.99 | 0.00 |  | 1.44 | 15.43 |  | No |  | No | N/A | 0.00 |  |  | N/A
04/08/2026 | 111-9637625-2277804 | Team 2 |  | 1 | USD | 46.88 | 0.00 | 0.00 | 4.83 | 51.71 | Closed | GIX PAY |  |  | Youngpyung Lee | yplee9487@gmail.com | N/A | N/A | N/A | N/A | N/A | 1iDTFmsZDBo42DZ0xpZf | 04/10/2026 | 51.71 | Visa | ="3832" | Business, Industrial, & Scientific Supplies Basic | B0BL772BVX | [10pcs/Pack] 8mm x 500mm Linear Motion Rod Shaft Guide, 10PCS 8mm Steel Rod for 3D Printer and CNC Machine (Diameter:8mm, 500mm / 19.685 inch) | ="26110000" | Power Generation and Distribution Machinery and Accessories | Batteries and generators and kinetic power transmission | Batteries and generators and kinetic power transmission | Batteries and generators and kinetic power transmission |  | BUVVTPU | BUVVTPU |  | ZH-8DG10 | ZH-8DG10 | New |  | N/A | 46.88 | 1 | 46.88 | 0.00 |  | 4.83 | 51.71 |  | No |  | No | N/A | 0.00 |  |  | N/A
04/07/2026 | 111-7618328-3672250 | Team 2 |  | 4 | USD | 35.72 | 2.99 | -2.99 | 3.68 | 39.40 | Closed | GIX PAY |  |  | Youngpyung Lee | yplee9487@gmail.com | N/A | N/A | N/A | N/A | N/A | 1RVP9LRkoeOQtJ1WlnIn | 04/08/2026 | 39.40 | Visa | ="3832" | Business, Industrial, & Scientific Supplies Basic | B07BT6N12L | WINSINN GT2 Timing Belt Pulley 20 Teeth, 5mm Bore, for 10mm Width Belt - Ideal for Automation, Robotics, Precision Machinery (5-Pack) | ="26111800" | Power Generation and Distribution Machinery and Accessories | Batteries and generators and kinetic power transmission | Drive components | Drive components |  | WINSINN | WINSINN |  | TBL10MM205 | TBL10MM205 | New |  | N/A | 6.88 | 2 | 13.76 | 1.49 | -1.49 | 1.42 | 15.18 |  | No |  | No | Quantity Discount | 2.22 |  |  | N/A
04/07/2026 | 111-7618328-3672250 | Team 2 |  | 4 | USD | 35.72 | 2.99 | -2.99 | 3.68 | 39.40 | Closed | GIX PAY |  |  | Youngpyung Lee | yplee9487@gmail.com | N/A | N/A | N/A | N/A | N/A | 1RVP9LRkoeOQtJ1WlnIn | 04/08/2026 | 39.40 | Visa | ="3832" | Business, Industrial, & Scientific Supplies Basic | B0B38GX54H | STEPPERONLINE 1 Pack Nema 17 Stepper Motor Bipolar 1.5A 42Ncm 42x42x38mm 1.8deg 4 Wires with 1m Cable and Connector | ="26111500" | Power Generation and Distribution Machinery and Accessories | Batteries and generators and kinetic power transmission | Kinetic power transmission | Kinetic power transmission |  | STEPPERONLINE | STEPPERONLINE |  | 17HE15-1504S | 17HE15-1504S | New |  | N/A | 10.98 | 2 | 21.96 | 1.50 | -1.50 | 2.26 | 24.22 |  | No |  | No | Business Price | 0.02 |  |  | N/A
04/07/2026 | 111-7618352-6936249 | Team 2 |  | 1 | USD | 11.98 | 0.00 | 0.00 | 1.23 | 13.21 | Closed | GIX PAY |  |  | Youngpyung Lee | yplee9487@gmail.com | N/A | N/A | N/A | N/A | N/A | 3A1s0Y93849QuRdTEqxw | 04/07/2026 | 13.21 | Visa | ="3832" | Business, Industrial, & Scientific Supplies Basic | B087WPGQ8T | 12 Pcs LM8UU Linear Ball Bearings, 8mm Bore Dia, 15mm OD, 24mm Length with Double Side Rubber Seal Great for CNC, 3D Printer | ="26111500" | Power Generation and Distribution Machinery and Accessories | Batteries and generators and kinetic power transmission | Kinetic power transmission | Kinetic power transmission |  | Edoneery | Edoneery |  | LM8UU | BearingLM8UU-12 Pcs | New |  | N/A | 11.98 | 1 | 11.98 | 0.00 |  | 1.23 | 13.21 |  | No |  | No | Business Price | 0.01 |  |  | N/A
04/07/2026 | 111-7618352-6936249 | Team 2 |  | 1 | USD | 11.98 | 0.00 | 0.00 | 1.23 | 13.21 | Closed | GIX PAY |  |  | Youngpyung Lee | yplee9487@gmail.com | N/A | N/A | N/A | N/A | N/A | N/A | N/A | N/A | N/A | N/A | Business, Industrial, & Scientific Supplies Basic | B0B2LPDSMC | 4PCS 8mmX 500mm (0.32" x 19.69") Case Hardened Chrome Plated Linear Motion Rods Linear Rail Rod Shaft for 3D Printer, DIY, CNC - Metric h8 Tolerance | ="26111500" | Power Generation and Distribution Machinery and Accessories | Batteries and generators and kinetic power transmission | Kinetic power transmission | Kinetic power transmission |  | akkacm | akkacm |  | Rods8-500MM-4P | Rods8-500MM-4P | New |  | N/A | 0.00 | 0 | 49.18 | 0.00 | -2.46 | 4.82 | 51.54 |  | No |  | No | Business Price | 0.00 |  |  | N/A
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

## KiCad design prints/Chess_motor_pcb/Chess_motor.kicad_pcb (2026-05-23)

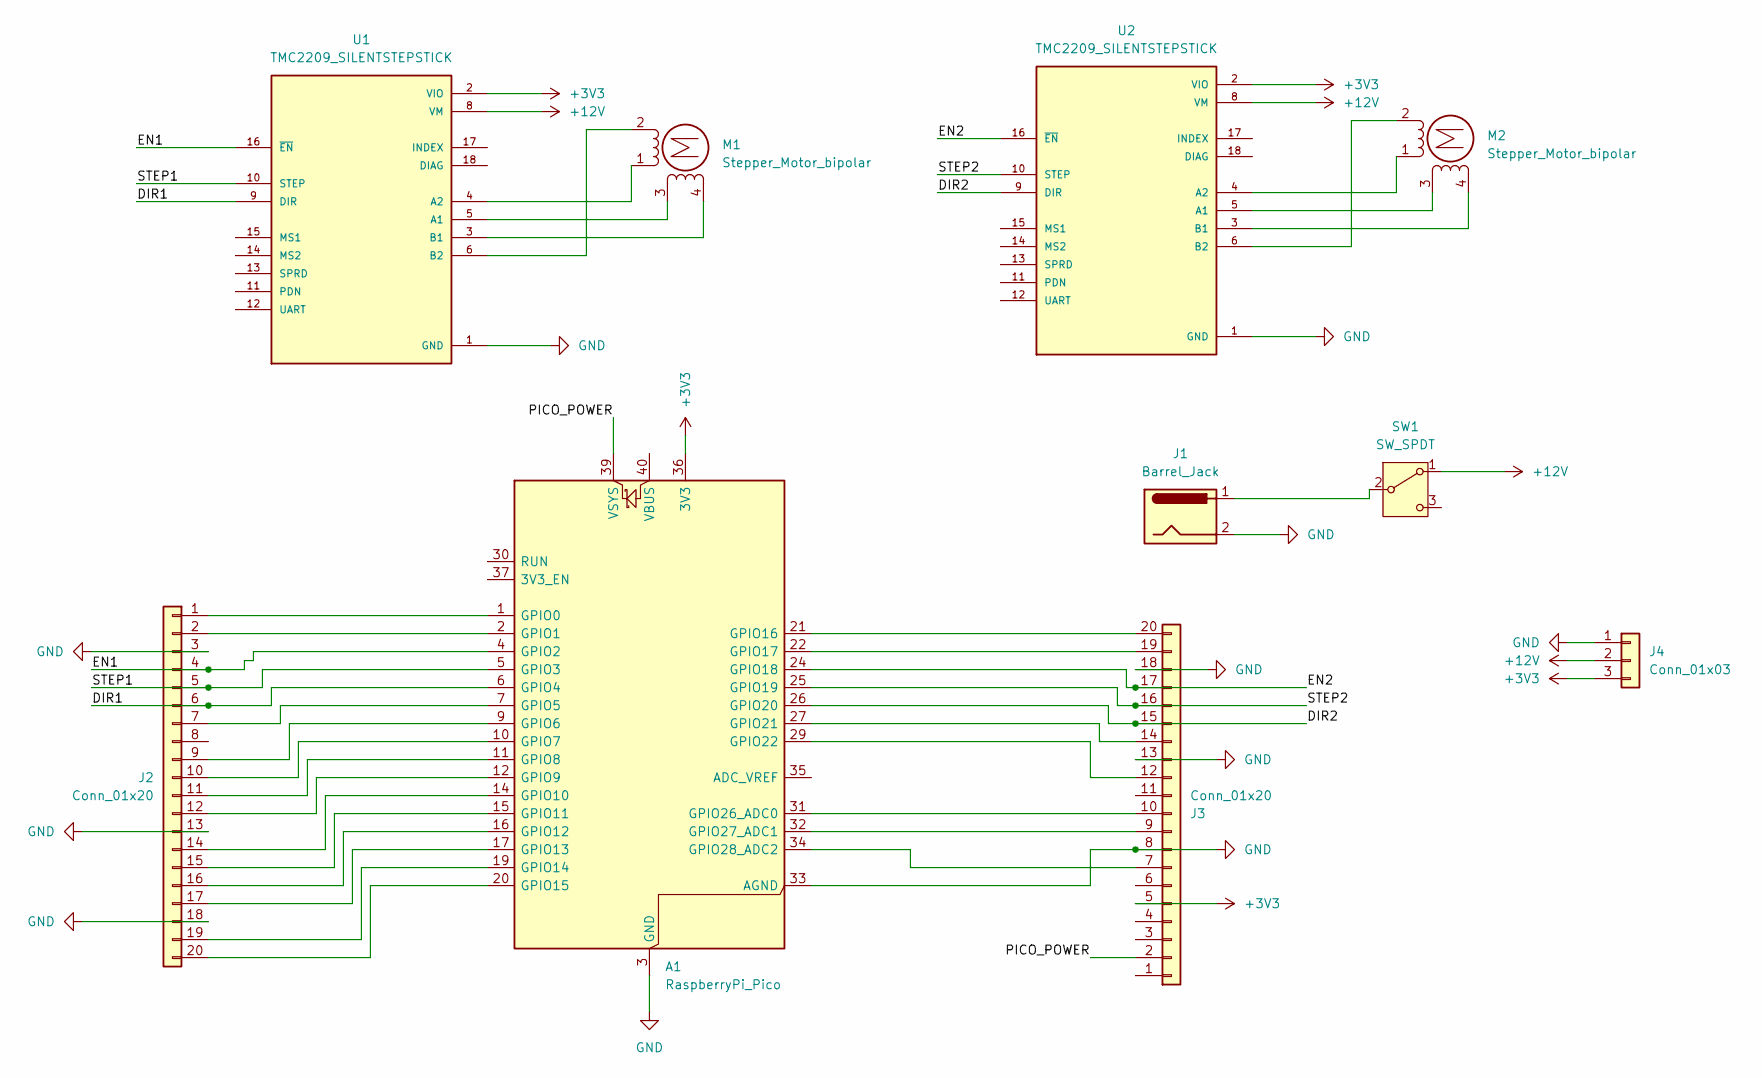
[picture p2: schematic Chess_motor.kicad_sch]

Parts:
A1: RaspberryPi_Pico; RaspberryPi_Pico_Common_THT
J1: Barrel_Jack; BarrelJack_Horizontal
J2, J3: Conn_01x20; PinHeader_1x20_P2.54mm_Vertical
J4: Conn_01x03; PinHeader_1x03_P2.54mm_Vertical
M1, M2: Stepper_Motor_bipolar; PinHeader_1x04_P2.54mm_Vertical
SW1: SW_SPDT; SW_Slide-03_Wuerth-WS-SLTV_10x2.5x6.4_P2.54mm
U1, U2: TMC2209_SILENTSTEPSTICK; MODULE_TMC2209_SILENTSTEPSTICK; PARTREV 1.20

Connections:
+3V3: A1.36 (3V3), J3.5, J4.3, U1.2 (VIO), U2.2 (VIO)
+12V: J4.2, SW1.1 (A), U1.8 (VM), U2.8 (VM)
/DIR1: A1.6 (GPIO4), J2.6, U1.9 (DIR)
/DIR2: A1.26 (GPIO20), J3.15, U2.9 (DIR)
/EN1: A1.4 (GPIO2), J2.4, U1.16 (~EN)
/EN2: A1.24 (GPIO18), J3.17, U2.16 (~EN)
/PICO_POWER: A1.39 (VSYS), J3.2
/STEP1: A1.5 (GPIO3), J2.5, U1.10 (STEP)
/STEP2: A1.25 (GPIO19), J3.16, U2.10 (STEP)
GND: A1.3 (GND), A1.8 (GND), A1.13 (GND), A1.18 (GND), A1.23 (GND), A1.28 (GND), A1.33 (AGND), A1.38 (GND), J1.2, J2.3, J2.13, J2.18, J3.8, J3.13, J3.18, J4.1, U1.1 (GND), U1.7 (GND), U2.1 (GND), U2.7 (GND)
unnamed: A1.1 (GPIO0), J2.1
unnamed: A1.2 (GPIO1), J2.2
unnamed: A1.7 (GPIO5), J2.7
unnamed: A1.9 (GPIO6), J2.9
unnamed: A1.10 (GPIO7), J2.10
unnamed: A1.11 (GPIO8), J2.11
unnamed: A1.12 (GPIO9), J2.12
unnamed: A1.14 (GPIO10), J2.14
unnamed: A1.15 (GPIO11), J2.15
unnamed: A1.16 (GPIO12), J2.16
unnamed: A1.17 (GPIO13), J2.17
unnamed: A1.19 (GPIO14), J2.19
unnamed: A1.20 (GPIO15), J2.20
unnamed: A1.21 (GPIO16), J3.20
unnamed: A1.22 (GPIO17), J3.19
unnamed: A1.27 (GPIO21), J3.14
unnamed: A1.29 (GPIO22), J3.12
unnamed: A1.31 (GPIO26_ADC0), J3.10
unnamed: A1.32 (GPIO27_ADC1), J3.9
unnamed: A1.34 (GPIO28_ADC2), J3.7
unnamed: M1.2 (-), U1.6 (B2)
unnamed: M2.2 (-), U2.6 (B2)
unnamed: J1.1, SW1.2 (B)
unnamed: M1.3, U1.5 (A1)
unnamed: M1.1, U1.4 (A2)
unnamed: M1.4, U1.3 (B1)
unnamed: M2.3, U2.5 (A1)
unnamed: M2.1, U2.4 (A2)
unnamed: M2.4, U2.3 (B1)

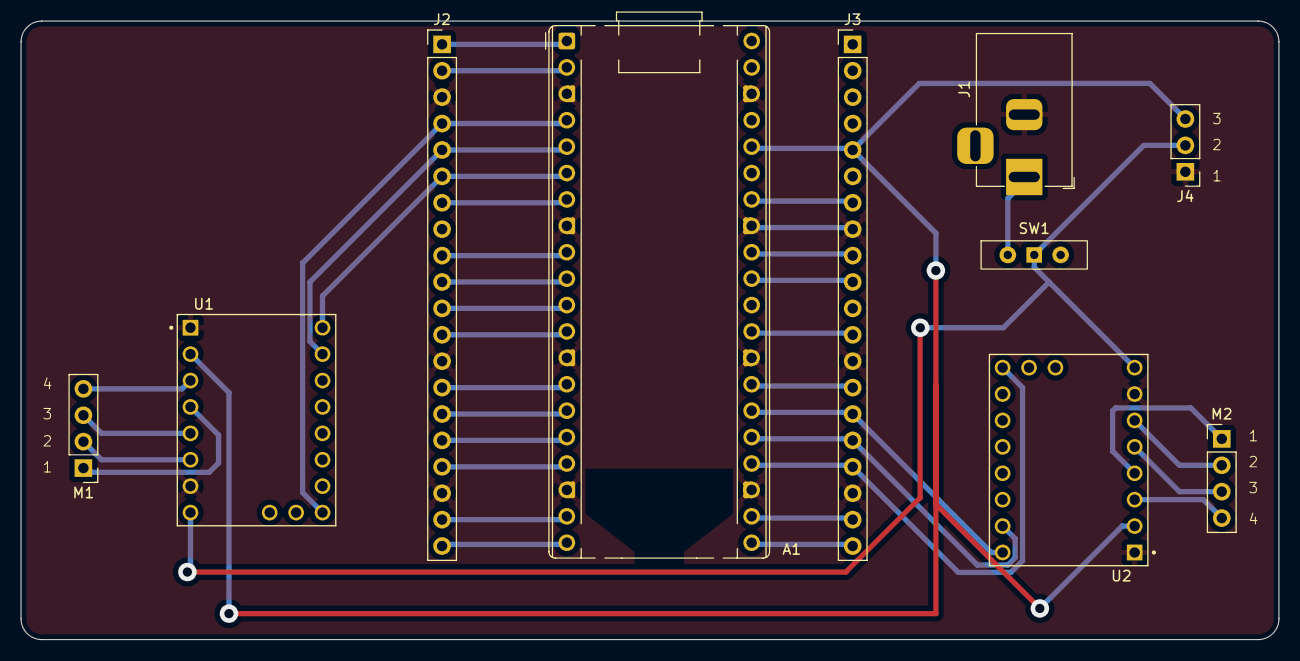
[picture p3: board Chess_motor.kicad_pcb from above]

Board: 2 copper layers, 121.0 x 59.5 mm, 10 parts (0 on the bottom side), 39 nets.

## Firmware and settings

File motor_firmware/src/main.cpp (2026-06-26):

#include <Arduino.h>
#include <WiFi.h>
#include <esp_now.h>
#include <esp_wifi.h>
#include <string.h>

#include "StepperMotor.h"
#include "CoreXY.h"
#include "Electromagnet.h"
#include "ChessGame.h"
#include "MovePlanner.h"
#include "NullSerial.h"  // disables Serial — magnet shares UART0 pins (GPIO1/3)

// ---- pins (ESP32 DevKit GPIO numbers) ----
// Constructor arg order: StepperMotor(EN, STEP, DIR), Electromagnet(IN1, IN2, ENA).
// Stepper 1 (TMC2209): EN=GPIO23, STEP=GPIO32, DIR=GPIO33
// Stepper 2 (TMC2209): EN=GPIO2,  STEP=GPIO5,  DIR=GPIO4
//   GPIO2 strapping, idles LOW; TMC2209 EN active-low so LOW = enabled (safe at boot).
//   GPIO5 strapping, safe as output.
StepperMotor motorA(23, 32, 33);
StepperMotor motorB(2, 5, 4);
CoreXY xy(motorA, motorB);

// Magnet H-bridge (L298N): IN1=GPIO3, IN2=GPIO15, ENA=GPIO1.
//   ⚠️ ENA=GPIO1 (U0TXD), IN1=GPIO3 (U0RXD) are the UART0 console pins, so
//   Serial is disabled board-wide via NullSerial.h to keep it off the magnet.
//   GPIO1 needs a 10k pull-down (magnet off at boot); GPIO15 strapping idles HIGH.
Electromagnet magnet(3, 15, 1);
static constexpr bool MAGNET_ENABLED = true;

// Travel speed when the carriage is empty vs. carrying a piece.
// Pieces slide more reliably at lower speed.
static constexpr int TRAVEL_STEPS_PER_SEC = 4000;
static constexpr int CARRY_STEPS_PER_SEC  = 1500;

// Homing / calibration
static constexpr int   HOME_SPEED_STEPS_PER_SEC = 1200;
static constexpr float KNOWN_X_CM               = 45.0f;
static constexpr float KNOWN_Y_CM               = 45.5f;
static constexpr int   HOME_BACKOFF_STEPS        = 300;  // steps to back off after hitting a switch

// A1 = (3.8, 5.5); each letter = +5.0 cm X, each number = +5.0 cm Y
static constexpr float SQUARE_ORIGIN_X = 4.0f;
static constexpr float SQUARE_ORIGIN_Y = 5.0f;
static constexpr float SQUARE_STEP_X   = 4.625f;
static constexpr float SQUARE_STEP_Y   = 4.625f;

ChessGame   game;
MovePlanner planner(game, {SQUARE_ORIGIN_X, SQUARE_ORIGIN_Y, SQUARE_STEP_X, SQUARE_STEP_Y});

// ---------- ESP-NOW transport ----------

// The control firmware connects to this SSID. We scan for it to discover
// the AP's channel so ESP-NOW lands on the same channel without blind hopping.
// Keep this in sync with control_firmware/src/main.cpp WIFI_SSID.
static const char* CONTROL_WIFI_SSID = "robolab_5";

// Control firmware's MAC — hardcoded so we skip the broadcast pairing
// handshake. Read once from the control's serial banner. Update if the
// control board is ever swapped.
static const uint8_t CONTROL_MAC[6] = {0x1C, 0xDB, 0xD4, 0x5C, 0x9A, 0xF8};

static constexpr uint8_t MAX_CANDIDATE_CHANNELS = 8;
static uint8_t  candidateChannels[MAX_CANDIDATE_CHANNELS] = {};
static uint8_t  candidateCount = 0;
static uint8_t  candidateIndex = 0;
static uint8_t  currentChannel = 1;
static volatile bool channelLocked = false;
static volatile bool needsRescan   = true;
static volatile bool tryNextChannel = false;

struct RxMsg { uint16_t len; char data[200]; };
static QueueHandle_t rxQueue;

static void sendRaw(const char* s, size_t len) {
    esp_now_send(CONTROL_MAC, (const uint8_t*)s, len);
}

#if defined(ESP_ARDUINO_VERSION_MAJOR) && ESP_ARDUINO_VERSION_MAJOR >= 3
static void onEspNowSent(const uint8_t* mac, esp_now_send_status_t status) {
#else
static void onEspNowSent(const uint8_t* mac, esp_now_send_status_t status) {
#endif
    if (status == ESP_NOW_SEND_SUCCESS) return;
    Serial.printf("[ESP-NOW] send FAILED to %02X:%02X:%02X:%02X:%02X:%02X\n",
                  mac[0], mac[1], mac[2], mac[3], mac[4], mac[5]);
    // Ask pairingTick() to advance to the next candidate channel from the
    // last scan. If we run out, it triggers a full rescan.
    tryNextChannel = true;
}

#if defined(ESP_ARDUINO_VERSION_MAJOR) && ESP_ARDUINO_VERSION_MAJOR >= 3
static void onEspNowRecv(const esp_now_recv_info_t* info, const uint8_t* data, int len) {
    const uint8_t* src = info->src_addr;
#else
static void onEspNowRecv(const uint8_t* src, const uint8_t* data, int len) {
#endif
    if (len <= 0) return;
    if (memcmp(src, CONTROL_MAC, 6) != 0) return;  // ignore anyone else

    RxMsg m{};
    m.len = (len < (int)sizeof(m.data) - 1) ? len : (int)sizeof(m.data) - 1;
    memcpy(m.data, data, m.len);
    m.data[m.len] = '\0';
    BaseType_t hpw = pdFALSE;
    xQueueSendFromISR(rxQueue, &m, &hpw);
}

static void setChannel(uint8_t ch) {
    currentChannel = ch;
    esp_wifi_set_promiscuous(true);
    esp_wifi_set_channel(ch, WIFI_SECOND_CHAN_NONE);
    esp_wifi_set_promiscuous(false);
}

// Try the channel at candidateChannels[candidateIndex]. Returns false if the
// index is past the end of the list (caller should rescan).
static bool tryCurrentCandidate() {
    if (candidateIndex >= candidateCount) return false;
    uint8_t ch = candidateChannels[candidateIndex];
    setChannel(ch);
    channelLocked = true;
    Serial.printf("[ESP-NOW] trying channel %u (candidate %u/%u)\n",
                  ch, candidateIndex + 1, candidateCount);
    return true;
}

static void scanForControlChannel() {
    Serial.printf("[ESP-NOW] scanning for SSID '%s'...\n", CONTROL_WIFI_SSID);
    int32_t n = WiFi.scanNetworks();
    candidateCount = 0;
    for (int32_t i = 0; i < n && candidateCount < MAX_CANDIDATE_CHANNELS; i++) {
        if (!strcmp(CONTROL_WIFI_SSID, WiFi.SSID(i).c_str())) {
            uint8_t ch = (uint8_t)WiFi.channel(i);
            // Skip duplicates.
            bool seen = false;
            for (uint8_t j = 0; j < candidateCount; j++) {
                if (candidateChannels[j] == ch) { seen = true; break; }
            }
            if (!seen) candidateChannels[candidateCount++] = ch;
        }
    }
    WiFi.scanDelete();
    needsRescan    = false;
    tryNextChannel = false;
    candidateIndex = 0;

    if (candidateCount > 0) {
            tryCurrentCandidate();
    } else {
        channelLocked = false;
        Serial.printf("[ESP-NOW] SSID '%s' not found — will retry\n", CONTROL_WIFI_SSID);
    }
}

static void espNowInit() {
    WiFi.mode(WIFI_STA);
    if (esp_now_init() != ESP_OK) {
        Serial.println("[ESP-NOW] init failed");
        return;
    }
    esp_now_register_send_cb(onEspNowSent);
    esp_now_register_recv_cb(onEspNowRecv);

    // Register control as our only peer. Channel 0 = current WiFi channel.
    esp_now_peer_info_t p = {};
    memcpy(p.peer_addr, CONTROL_MAC, 6);
    p.channel = 0;
    p.encrypt = false;
    if (esp_now_add_peer(&p) != ESP_OK) {
        Serial.println("[ESP-NOW] esp_now_add_peer failed");
    }

    Serial.println("\n========================================");
    Serial.printf("  MOTOR MAC: %s\n", WiFi.macAddress().c_str());
    Serial.printf("  Control peer: %02X:%02X:%02X:%02X:%02X:%02X\n",
                  CONTROL_MAC[0], CONTROL_MAC[1], CONTROL_MAC[2],
                  CONTROL_MAC[3], CONTROL_MAC[4], CONTROL_MAC[5]);
    Serial.println("========================================\n");
    scanForControlChannel();
}

// Called from loop(). At boot or after a rescan request, runs the SSID scan.
// After send failures, advances to the next channel from the last scan; if
// the list is exhausted, triggers a fresh rescan.
//
// Throttle: only one channel change per ~200 ms — otherwise a burst of
// failed ACKs/DONEs in quick succession could spin us through the list
// before the radio actually settles on each channel.
static uint32_t lastChannelChangeMs = 0;
static constexpr uint32_t CHANNEL_CHANGE_THROTTLE_MS = 200;

static void pairingTick() {
    if (needsRescan) { scanForControlChannel(); return; }

    if (tryNextChannel) {
        uint32_t now = millis();
        if (now - lastChannelChangeMs < CHANNEL_CHANGE_THROTTLE_MS) return;
        lastChannelChangeMs = now;
        tryNextChannel = false;

        candidateIndex++;
        if (!tryCurrentCandidate()) {
            // Ran out of candidates — rescan to refresh the list.
            Serial.println("[ESP-NOW] candidates exhausted — rescanning");
            needsRescan = true;
        }
    }
}

// ---------- protocol output ----------

static void proto(const String& line) {
    sendRaw(line.c_str(), line.length());
    Serial.print("> ");
    Serial.println(line);
}

static char pieceChar(const Piece& p) {
    char c = '.';
    switch (p.type) {
        case PAWN:   c = 'p'; break;
        case ROOK:   c = 'r'; break;
        case KNIGHT: c = 'n'; break;
        case BISHOP: c = 'b'; break;
        case QUEEN:  c = 'q'; break;
        case KING:   c = 'k'; break;
        default:     return '.';
    }
    return p.color == WHITE ? (char)toupper(c) : c;
}

static void sendState() {
    String s = "STATE:";
    for (int row = 8; row >= 1; --row) {
        for (char col = 'A'; col <= 'H'; ++col) {
            s += pieceChar(game.getPieceAt({col, row}));
        }
    }
    s += ' ';
    s += (game.getTurn() == WHITE) ? 'w' : 'b';
    proto(s);
}

static void sendTurn() {
    proto(game.getTurn() == WHITE ? "TURN:WHITE" : "TURN:BLACK");
}

// ---------- input parsing ----------

static bool parseSquare(const String& s, Position& out) {
    if (s.length() < 2) return false;
    char col = s.charAt(0);
    int  row = s.substring(1).toInt();
    if (col < 'A' || col > 'H' || row < 1 || row > 8) return false;
    out = {col, row};
    return true;
}

static const char* turnStr(PieceColor c) {
    return c == WHITE ? "WHITE" : c == BLACK ? "BLACK" : "?";
}

static const char* pieceTypeStr(PieceType t) {
    switch (t) {
        case PAWN:   return "Pawn";
        case ROOK:   return "Rook";
        case KNIGHT: return "Knight";
        case BISHOP: return "Bishop";
        case QUEEN:  return "Queen";
        case KING:   return "King";
        default:     return "(empty)";
    }
}

static void printSquare(const Position& p) {
    if (p == kNoSquare) Serial.print("off-board");
    else                Serial.printf("%c%d", p.col, p.row);
}

static void performCalibration();  // forward declaration — defined before setup()

static void drainBusyInput() {
    RxMsg pending;
    while (xQueueReceive(rxQueue, &pending, 0) == pdTRUE) {
        proto("ILLEGAL:busy");
    }
}

static void executeMove(Position from, Position to) {
    Piece moving   = game.getPieceAt(from);
    Piece captured = game.getPieceAt(to);

    if (!planner.startMove(from, to)) {
        proto(String("ILLEGAL:") + from.col + from.row + ":" + to.col + to.row);
        return;
    }

    {
        String ack = "ACK:";
        ack += from.col; ack += from.row; ack += ':';
        ack += to.col;   ack += to.row;
        proto(ack);
    }

    Serial.printf("  Moving %s %s: %c%d -> %c%d",
                  turnStr(moving.color), pieceTypeStr(moving.type),
                  from.col, from.row, to.col, to.row);
    if (captured.type != NONE) {
        Serial.printf("  (captures %s %s)",
                      turnStr(captured.color), pieceTypeStr(captured.type));
    }
    Serial.println();

    while (!planner.isMoveDone()) {
        if (xy.limitHit()) {
            Serial.println("  LIMIT HIT — recalibrating");
            if (MAGNET_ENABLED) magnet.off();
            proto("ILLEGAL:limit-hit");
            performCalibration();
            game.reset();
            sendState();
            sendTurn();
            return;
        }
        Step s = planner.peekNextStep();
        switch (s.type) {
            case MOVE_TO:
                Serial.print("  MOVE_TO ");
                printSquare(s.target);
                Serial.println();
                xy.moveToCm(s.x, s.y);
                break;
            case MAGNET_ON:
                Serial.printf("  MAGNET ON (%s) @ ",
                              s.polarity == WHITE ? "A/white" :
                              s.polarity == BLACK ? "B/black" : "?");
                printSquare(s.target);
                Serial.println();
                if (MAGNET_ENABLED) magnet.on(s.polarity);
                delay(300);  // let the field settle and grab the piece
                xy.setSpeed(CARRY_STEPS_PER_SEC);
                break;
            case MAGNET_OFF:
                Serial.print("  MAGNET OFF @ ");
                printSquare(s.target);
                Serial.println();
                delay(150);
                if (MAGNET_ENABLED) magnet.off();
                xy.setSpeed(TRAVEL_STEPS_PER_SEC);
                break;
        }
        planner.nextStep();
        drainBusyInput();
    }

    drainBusyInput();

    String done = "DONE:";
    done += from.col; done += from.row; done += ':';
    done += to.col;   done += to.row;
    proto(done);

    GameResult result = game.getResult();
    switch (result) {
        case GAME_CHECKMATE:
            proto(game.getTurn() == WHITE ? "CHECKMATE:WHITE" : "CHECKMATE:BLACK");
            Serial.printf("  Checkmate! %s wins.\n",
                          game.getTurn() == WHITE ? "Black" : "White");
            break;
        case GAME_STALEMATE:
            proto("STALEMATE");
            Serial.println("  Stalemate — draw.");
            break;
        case GAME_CHECK:
            proto(game.getTurn() == WHITE ? "CHECK:WHITE" : "CHECK:BLACK");
            sendTurn();
            Serial.printf("  Check! %s to move.\n", turnStr(game.getTurn()));
            break;
        default:
            sendTurn();
            Serial.printf("  Move done. Next turn: %s\n", turnStr(game.getTurn()));
            break;
    }
}

static void handleCommand(String input) {
    input.trim();
    input.toUpperCase();
    if (input.length() == 0) return;

    Serial.printf("[cmd] %s\n", input.c_str());

    if (input == "RESET") {
        game.reset();
        Serial.println("  Game reset.");
        sendState();
        sendTurn();
        return;
    }

    if (input == "STATE?") {
        sendState();
        sendTurn();
        return;
    }

    if (!input.startsWith("MOVE:")) {
        proto("ILLEGAL:bad-format");
        return;
    }

    String body = input.substring(5);
    int sep = body.indexOf(':');
    if (sep < 0) {
        proto("ILLEGAL:bad-format");
        return;
    }

    String fromStr = body.substring(0, sep);   fromStr.trim();
    String toStr   = body.substring(sep + 1);  toStr.trim();

    Position from{}, to{};
    if (!parseSquare(fromStr, from) || !parseSquare(toStr, to)) {
        proto("ILLEGAL:bad-square");
        return;
    }

    Serial.printf("  %c%d -> %c%d\n", from.col, from.row, to.col, to.row);
    executeMove(from, to);
}

static void performCalibration() {
    Serial.println("[CAL] Starting calibration...");
    xy.setSpeed(HOME_SPEED_STEPS_PER_SEC);
    xy.clearBounds();

    // ---- X axis ----
    Serial.println("[CAL] Homing -X...");
    xy.homeToLimit(/*xAxis=*/true, /*positive=*/false, HOME_SPEED_STEPS_PER_SEC);
    xy.setPosition(0, xy.getY());
    xy.moveBy(HOME_BACKOFF_STEPS, 0);   // back off so switch releases
    delay(150);

    Serial.println("[CAL] Measuring +X...");
    long xSteps = xy.homeToLimit(true, true, HOME_SPEED_STEPS_PER_SEC);
    xy.moveBy(-HOME_BACKOFF_STEPS, 0);  // back off from +X
    delay(150);

    // ---- Y axis ----
    Serial.println("[CAL] Homing -Y...");
    xy.homeToLimit(/*xAxis=*/false, /*positive=*/false, HOME_SPEED_STEPS_PER_SEC);
    xy.setPosition(xy.getX(), 0);
    xy.moveBy(0, HOME_BACKOFF_STEPS);   // back off so switch releases
    delay(150);

    Serial.println("[CAL] Measuring +Y...");
    long ySteps = xy.homeToLimit(false, true, HOME_SPEED_STEPS_PER_SEC);
    xy.moveBy(0, -HOME_BACKOFF_STEPS);  // back off from +Y
    delay(150);

    // ---- Compute steps/cm ----
    float spcX = (float)xSteps / KNOWN_X_CM;
    float spcY = (float)ySteps / KNOWN_Y_CM;
    float spc  = (spcX + spcY) / 2.0f;
    xy.setStepsPerCm(spc);
    xy.setMaxBounds(xSteps, ySteps);

    Serial.printf("[CAL] X: %ld steps (%.1f/cm)  Y: %ld steps (%.1f/cm)  avg: %.1f/cm\n",
                  xSteps, spcX, ySteps, spcY, spc);

    // ---- Park near origin ----
    xy.setPosition(xSteps - HOME_BACKOFF_STEPS, ySteps - HOME_BACKOFF_STEPS);
    xy.moveToCm(SQUARE_ORIGIN_X - SQUARE_STEP_X, SQUARE_ORIGIN_Y - SQUARE_STEP_Y);
    xy.setSpeed(TRAVEL_STEPS_PER_SEC);

    Serial.println("[CAL] Calibration done.");
}

void setup() {
    Serial.begin(115200);
    delay(1000);
    Serial.println("[ChessBot] boot");

    rxQueue = xQueueCreate(8, sizeof(RxMsg));
    espNowInit();

    xy.begin();
    xy.setSpeed(TRAVEL_STEPS_PER_SEC);

    // Limit switches — active-LOW (switch connects GPIO to GND; 10kΩ pull-up to 3.3V).
    CoreXY::LimitPins limits;
    limits.xMinus  = 26;
    limits.xPlus   = 25;
    limits.yMinus1 = 34;
    limits.yMinus2 = 35;
    limits.yPlus1  = 36;
    limits.yPlus2  = 39;
    xy.setLimitSwitches(limits, /*activeHigh=*/false);

    if (MAGNET_ENABLED) magnet.begin();

    performCalibration();

    Serial.println("[ChessBot] Ready. Waiting for pairing...");
}

void loop() {
    pairingTick();

    // Drain inbound ESP-NOW messages.
    RxMsg m;
    while (xQueueReceive(rxQueue, &m, 0) == pdTRUE) {
        handleCommand(String(m.data));
    }

    // USB serial for local debugging / manual commands.
    if (Serial.available()) {
        String input = Serial.readStringUntil('\n');
        handleCommand(input);
    }

    // Once the channel scan locks in, broadcast initial state once so the
    // control / UI start with an accurate view of the board.
    static bool announcedReady = false;
    if (channelLocked && !announcedReady) {
        announcedReady = true;
        Serial.printf("[ESP-NOW] ready on channel %u\n", currentChannel);
        sendState();
        sendTurn();
    }
}

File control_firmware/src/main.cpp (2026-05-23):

// Chess voice controller — Arduino, button-triggered Whisper test
//
// Press BOOT button → record 3 s (or until silence) → POST to Whisper →
// parse "e2 to e4" → print result. No wake word, no UART.

#include <Arduino.h>
#include <WiFi.h>
#include <WiFiClientSecure.h>
#include <HTTPClient.h>
#include <ArduinoJson.h>
#include <driver/i2s.h>
#include <esp_heap_caps.h>

#include "pico_link.h"
#include "ui_link.h"
#include "config.h"  // WIFI_SSID, WIFI_PASSWORD, OPENAI_API_KEY, UI_SERVER_IP — gitignored

// ── Pins (XIAO ESP32-S3) ─────────────────────────────────────────────────────
#define I2S_PORT     I2S_NUM_0
#define I2S_SD_PIN   D0   // mic DOUT
#define I2S_SCK_PIN  D1   // BCLK
#define I2S_WS_PIN   D2   // LRCLK
#define BUTTON_PIN   D3    // BOOT button (GPIO 0, active LOW, internal pullup)
// Motor controller is reached over ESP-NOW now; no UART pins required.

#define LED_ON  LOW
#define LED_OFF HIGH

// ── Audio ────────────────────────────────────────────────────────────────────
#define SAMPLE_RATE         16000
#define MAX_RECORD_MS       3000
#define MAX_SAMPLES         (SAMPLE_RATE * MAX_RECORD_MS / 1000)  // 48 000
#define CHUNK_SAMPLES       512
#define SILENCE_RMS_THRESH  400   // lower = more sensitive to faint speech (less likely to call it silent)
#define SILENCE_CHUNKS      30    // ~0.96 s of silence required before early stop
#define MIN_RECORD_CHUNKS   (SAMPLE_RATE / CHUNK_SAMPLES / 2)
#define I2S_DOWNSHIFT       14   // ICS-43432 is 24-bit-in-32-bit; shift to 16-bit

static int16_t *audioBuf     = nullptr;
static size_t   audioSamples = 0;


// ─────────────────────────────────────────────────────────────────────────────
// WiFi
// ─────────────────────────────────────────────────────────────────────────────
static bool ensureWiFi() {
    if (WiFi.status() == WL_CONNECTED) return true;
    Serial.print("[WiFi] Connecting");
    // AP_STA (not just STA) — needed for stable WiFi + ESP-NOW coexistence.
    // Also disable WiFi power-save so ESP-NOW timing isn't disrupted by sleeps.
    WiFi.mode(WIFI_AP_STA);
    WiFi.setSleep(false);
    WiFi.begin(WIFI_SSID, WIFI_PASSWORD);
    unsigned long t0 = millis();
    while (WiFi.status() != WL_CONNECTED && millis() - t0 < 15000) {
        delay(500); Serial.print('.');
    }
    Serial.println();
    if (WiFi.status() != WL_CONNECTED) { Serial.println("[WiFi] Failed"); return false; }
    Serial.printf("[WiFi] %s\n", WiFi.localIP().toString().c_str());
    return true;
}


// ─────────────────────────────────────────────────────────────────────────────
// I2S — 32-bit slot (ICS-43432 is 24-bit-in-32-bit)
// ─────────────────────────────────────────────────────────────────────────────
static void initI2S() {
    i2s_config_t cfg = {
        .mode                 = (i2s_mode_t)(I2S_MODE_MASTER | I2S_MODE_RX),
        .sample_rate          = SAMPLE_RATE,
        .bits_per_sample      = I2S_BITS_PER_SAMPLE_32BIT,
        .channel_format       = I2S_CHANNEL_FMT_ONLY_LEFT,
        .communication_format = I2S_COMM_FORMAT_STAND_I2S,
        .intr_alloc_flags     = ESP_INTR_FLAG_LEVEL1,
        .dma_buf_count        = 4,
        .dma_buf_len          = CHUNK_SAMPLES,
        .use_apll             = false,
        .tx_desc_auto_clear   = false,
        .fixed_mclk           = 0,
    };
    i2s_pin_config_t pins = {
        .mck_io_num   = I2S_PIN_NO_CHANGE,
        .bck_io_num   = I2S_SCK_PIN,
        .ws_io_num    = I2S_WS_PIN,
        .data_out_num = I2S_PIN_NO_CHANGE,
        .data_in_num  = I2S_SD_PIN,
    };
    ESP_ERROR_CHECK(i2s_driver_install(I2S_PORT, &cfg, 0, nullptr));
    ESP_ERROR_CHECK(i2s_set_pin(I2S_PORT, &pins));
}

// Read N int16 samples, downconverting from 32-bit slots.
static bool readI2S16(int16_t *out, size_t nSamples) {
    static int32_t buf32[CHUNK_SAMPLES];
    size_t got = 0;
    if (i2s_read(I2S_PORT, buf32, nSamples * sizeof(int32_t), &got, portMAX_DELAY) != ESP_OK)
        return false;
    size_t n = got / sizeof(int32_t);
    for (size_t i = 0; i < n; i++) {
        int32_t s = buf32[i] >> I2S_DOWNSHIFT;
        if (s >  32767) s =  32767;
        if (s < -32768) s = -32768;
        out[i] = (int16_t)s;
    }
    return n == nSamples;
}


// ─────────────────────────────────────────────────────────────────────────────
// Recording
// ─────────────────────────────────────────────────────────────────────────────
static bool isSilent(const int16_t *buf, size_t n) {
    int64_t rms = 0;
    for (size_t i = 0; i < n; i++) rms += (int64_t)buf[i] * buf[i];
    return (rms / (int64_t)n) < (int64_t)SILENCE_RMS_THRESH * SILENCE_RMS_THRESH;
}

static bool recordAudio() {
    audioSamples = 0;
    int16_t chunk[CHUNK_SAMPLES];
    int silentRun = 0;
    const int totalChunks = MAX_SAMPLES / CHUNK_SAMPLES;
    int peak = 0;

    for (int c = 0; c < totalChunks; c++) {
        if (!readI2S16(chunk, CHUNK_SAMPLES)) continue;
        size_t n = CHUNK_SAMPLES;
        if (audioSamples + n > MAX_SAMPLES) n = MAX_SAMPLES - audioSamples;
        memcpy(audioBuf + audioSamples, chunk, n * 2);
        audioSamples += n;

        for (size_t i = 0; i < n; i++) {
            int v = chunk[i] < 0 ? -chunk[i] : chunk[i];
            if (v > peak) peak = v;
        }

        if (c >= MIN_RECORD_CHUNKS) {
            silentRun = isSilent(chunk, n) ? silentRun + 1 : 0;
            if (silentRun >= SILENCE_CHUNKS) {
                Serial.println("[REC] Silence → stopping early");
                break;
            }
        }
    }
    Serial.printf("[REC] %u samples (%.2f s), peak=%d/32767\n",
                  (unsigned)audioSamples, (float)audioSamples / SAMPLE_RATE, peak);
    return audioSamples > 0;
}


// ─────────────────────────────────────────────────────────────────────────────
// WAV builder (PCM 16-bit mono 16 kHz)
// ─────────────────────────────────────────────────────────────────────────────
static uint8_t *buildWAV(size_t &wavSize) {
    uint32_t dataBytes = audioSamples * 2;
    wavSize = 44 + dataBytes;
    uint8_t *w = (uint8_t *)heap_caps_malloc(wavSize, MALLOC_CAP_SPIRAM);
    if (!w) return nullptr;

    auto p32 = [&](int o, uint32_t v) { w[o]=v; w[o+1]=v>>8; w[o+2]=v>>16; w[o+3]=v>>24; };
    auto p16 = [&](int o, uint16_t v) { w[o]=v; w[o+1]=v>>8; };

    memcpy(w,    "RIFF", 4);  p32(4,  wavSize - 8);
    memcpy(w+8,  "WAVE", 4);
    memcpy(w+12, "fmt ", 4);  p32(16, 16);
    p16(20, 1); p16(22, 1);
    p32(24, SAMPLE_RATE);
    p32(28, SAMPLE_RATE * 2);
    p16(32, 2); p16(34, 16);
    memcpy(w+36, "data", 4);  p32(40, dataBytes);
    memcpy(w+44, audioBuf, dataBytes);
    return w;
}
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

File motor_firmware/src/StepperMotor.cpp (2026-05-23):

#include "StepperMotor.h"

StepperMotor::StepperMotor(int enPin, int stepPin, int dirPin)
    : _enPin(enPin), _stepPin(stepPin), _dirPin(dirPin),
      _enabled(false), _delayStartUs(4000), _delayUs(500), _stepCount(0) {}

void StepperMotor::begin() {
    pinMode(_enPin,   OUTPUT);
    pinMode(_stepPin, OUTPUT);
    pinMode(_dirPin,  OUTPUT);
    disable();
}

void StepperMotor::enable() {
    digitalWrite(_enPin, LOW);
    _enabled = true;
}

void StepperMotor::disable() {
    digitalWrite(_enPin, HIGH);
    _enabled = false;
}

void StepperMotor::setDirection(bool clockwise) {
    digitalWrite(_dirPin, clockwise ? HIGH : LOW);
}

// stepsPerSec -> converts to half-period delay in microseconds
void StepperMotor::setSpeed(int stepsPerSec) {
    _delayUs = 1000000L / (stepsPerSec * 2);
}

void StepperMotor::rampUp(int accelSteps) {
    for (int i = 0; i < accelSteps; i++) {
        long d = map(i, 0, accelSteps, _delayStartUs, _delayUs);
        _pulse(d);
    }
}

void StepperMotor::step() {
    _pulse(_delayUs);
    _stepCount++;
}

void StepperMotor::steps(int n) {
    for (int i = 0; i < n; i++) {
        step();
    }
}

void StepperMotor::_pulse(long halfPeriodUs) {
    digitalWrite(_stepPin, HIGH);
    delayMicroseconds(halfPeriodUs);
    digitalWrite(_stepPin, LOW);
    delayMicroseconds(halfPeriodUs);
}

void StepperMotor::stepOnce() {
    digitalWrite(_stepPin, HIGH);
    delayMicroseconds(2);
    digitalWrite(_stepPin, LOW);
    _stepCount++;
}

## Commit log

2026-05-23 Initial commit: Wizard Chess capstone project.
    Physical chess board with CoreXY gantry, ESP32-S3 voice/UI bridge, Pico motor firmware, and Next.js web UI.
    [Chess_motor-B_Cu.gbr, Chess_motor-B_Mask.gbr, Chess_motor-B_Paste.gbr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]
2026-06-26 Integrate teammate updates: attack animations, game modes, firmware board switch
    UI:
    - Add AttackAnimation + GameModeRow components and per-piece move/attack
    effect videos (UI/public/effects).
    - Rework RightPanel and /game page for game modes; add globals.css styling.
    - socket.ts: add pending-move timeout + proper useEffect ref handling.
    - stockfish.ts: AI engine improvements.
    Firmware:
    - motor_firmware: switch board to esp32dev, add esp32dev_macprint env and
    NullSerial.h; expand ChessGame/CoreXY/MovePlanner logic.
    - control_firmware: update MOTOR_MAC for the new motor board.
    [CoreXY.cpp, CoreXY.h, main.cpp]
